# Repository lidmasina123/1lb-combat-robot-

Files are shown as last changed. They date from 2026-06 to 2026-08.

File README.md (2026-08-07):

# Zagitis

**Zagitis** is a 1 lb combat robot with a unique weapon system. Unlike most robots in this weight class, which simply use a spinning weapon mounted directly to the chassis, Zagitis uses an **articulating weapon arm** with a spinning mass mounted at the end.

This allows the weapon to feed into an opponent more effectively, increasing the amount of damage it can deal.

The robot is designed to attack opponents from above, as the top armor on many 1 lb combat robots is significantly weaker than the front or sides.

I chose this design because many modern atveight robots are extremely similar—typically 4WD vertical eggbeaters. Building a robot that is only slightly better than existing designs is both difficult and expensive. Instead, Zagitis is designed to counter this common style by targeting their weaker top armor.





---

# Features

## 1. Fully Brushless Drive

The drive system is completely brushless, providing a better power-to-weight ratio, higher efficiency, and improved reliability.

## 2. Carbon Fiber + TPU Construction

The robot combines carbon fiber with TPU printed parts. This allows it to absorb impacts while remaining structurally rigid.

## 3. Compact Electronics

The robot uses **two Repeat Robotics dual-drive ESCs**, allowing all of the electronics to fit into a very compact chassis.

## 4. Narrow but Wide Design

The robot is narrow from the front while maintaining a wide wheelbase. This reduces the number of exposed sides where opponents can gain an advantage while improving stability.

## 5. 4S Battery

Most 1 lb combat robots run on **3S batteries**.

Zagitis uses a **4S battery** for increased power and faster weapon spin-up.

## 6. Two Configurations

The robot has two interchangeable configurations depending on the opponent.

- Vertical spinner configuration
- Horizontal spinner configuration

## 7. Tangent Drive

Unlike most 1 lb combat robots, which use smaller motors paired with gearboxes, Zagitis uses **tangent drive motors**.

This allows the use of larger, more powerful motors while eliminating the gearbox, reducing complexity and improving efficiency.

---

# Wiring Diagram

wiering diagram

---

# Bill of Materials

| Part | Link | Price | Qty | Total |
|---|---|---:|----:|---:|
| Drive Motors – Tangent 1406 | https://palmbeachbots.com/products/repeat-robotics-tangent-drive-motor-1406-1500kv | $18 | 2 | $36 |
| Arm Motor – 16 mm Brushed Planetary | https://palmbeachbots.com/products/repeat-robotics-16mm-brushed-planetary-motor | $17 | 1 | $17 |
| Weapon Motor – Repeat 2307 | https://www.aliexpress.com/item/1005007338658310.html | $15 | 1 | $15 |
| Repeat Robotics Dual Drive ESC | https://palmbeachbots.com/products/repeat-robotics-am32-dual-brushless-drive-esc-with-bec | $40 | 2 | $80 |
| FlySky FS-i4X Transmitter | https://palmbeachbots.com/products/flysky-fs-i4x-2-4ghz-4-channel-transmitter-with-receiver-afhds2a | $52 | 1 | $52 |
| FS2A Receiver | https://palmbeachbots.com/products/fs2a-4-channel-mini-receiver-afhds-2a-works-with-flysky-fs-i6 | $12 | 1 | $12 |

## Total Cost

**$212 USD**

---

# Assembly

This robot is designed to be easy to assemble and repair, making it quick to service between fights.

## Step 1 – Assemble the Drive Pods

First, assemble the two drive pods.

Each drive pod requires:

- 2 × M4 screws or shoulder bolts for the wheel
- 4 × M2 screws to mount the drive motor

Once assembled, make sure the wheel spins freely.

---

## Step 2 – Assemble the Weapon Arm

You will need:

- 1 × M4 bolt for the arm shaft
- 2 × M2 screws for the arm motor

Attach the arm motor first.

Press the gear onto the motor shaft.

Insert the arm shaft through one side of the chassis, through the arm gear (with both **4×8×3 mm bearings** installed), and out through the opposite side.

Finally, bolt the weapon arm to the arm gear and install the completed assembly into the chassis.

---

## Step 3 – Assemble the Chassis

Attach all mechanical components to the bottom carbon fiber plate using:

- 18 × 2.5 mm wood screws

---

## Step 4 – Install the Electronics

Install both dual-drive ESCs.

Wiring is straightforward:

- Connect each drive motor to one side of a dual-drive ESC.
- Connect both ESC signal wires to the receiver.
- Connect the weapon ESC and weapon motor.
- Connect the battery.
- Verify that all motors spin in the correct direction before securing the wiring.

---

## Step 5 – Finish Assembly

Install the top armor plates and secure them with the screws.

The robot is now fully assembled and ready for testing.

> **Note**
>
> More detailed assembly instructions with photos will be added once all of the parts have arrived and the robot has been fully assembled.

---

# Additional Information

- Approximately **130 g** of filament is required for all printed parts.
- All carbon fiber parts fit within a **100 mm × 200 mm × 1.5 mm** carbon fiber sheet.
- The robot is designed for fast maintenance and easy part replacement between fights.

---

# License

This project is open source.

Feel free to build, modify, and improve the design.

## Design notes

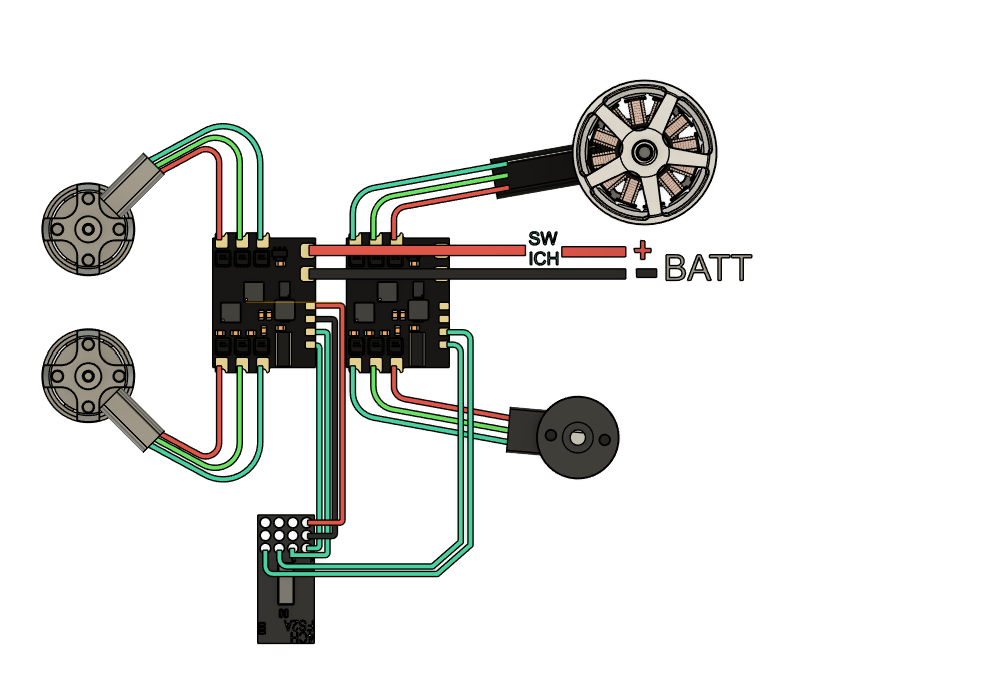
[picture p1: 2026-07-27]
wiering diagram.png

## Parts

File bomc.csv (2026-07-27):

 |  |  |  | bill of materials
part |  | price | quantity
driwe motors tangent 1406 | https://palmbeachbots.com/products/repeat-robotics-tangent-drive-motor-1406-1500kv | 18 | 2 | 36
arm motor 16mm Brushed Planetary Motor | https://palmbeachbots.com/products/repeat-robotics-16mm-brushed-planetary-motor | 17 | 1 | 17
weapon motor repat 2307 | https://www.aliexpress.com/item/1005007338658310.html | 15 | 1 | 15
esc | https://palmbeachbots.com/products/repeat-robotics-am32-dual-brushless-drive-esc-with-bec | 40 | 2 | 80
rc remote | https://palmbeachbots.com/products/flysky-fs-i4x-2-4ghz-4-channel-transmitter-with-receiver-afhds2a | 52 | 1 | 52
reciver | https://palmbeachbots.com/products/fs2a-4-channel-mini-receiver-afhds-2a-works-with-flysky-fs-i6 | 12 | 1 | 12
 |  | totoal | 212

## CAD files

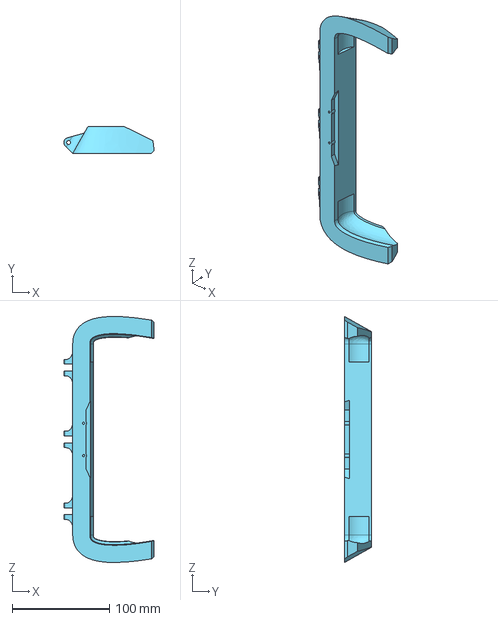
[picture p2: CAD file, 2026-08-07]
cad/cad/main body metal forks.step
93.1 x 27.5 x 253.4 mm

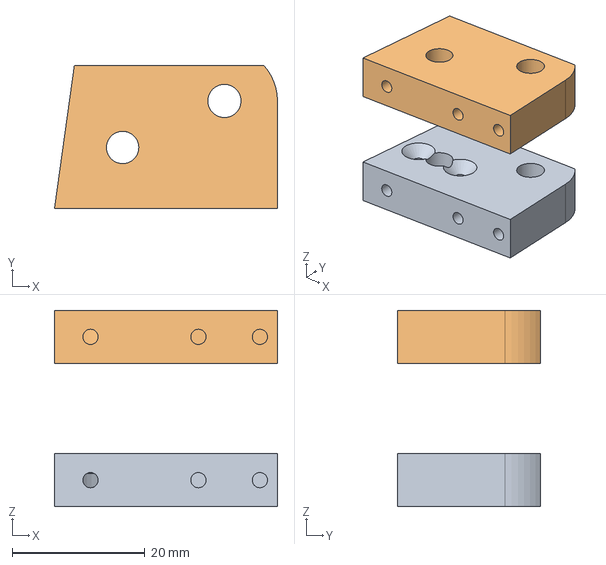
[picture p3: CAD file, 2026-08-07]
cad/cad/arm holder.step
33.6 x 21.5 x 29.6 mm

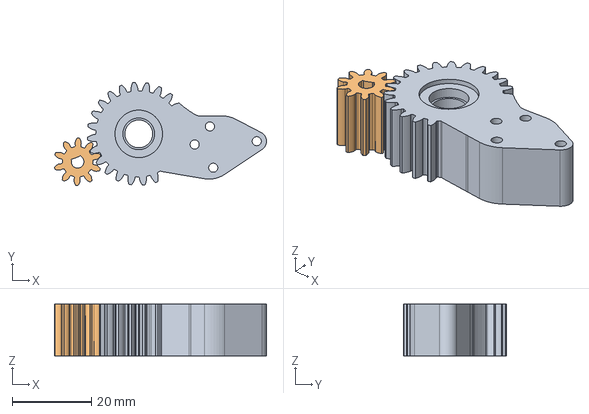
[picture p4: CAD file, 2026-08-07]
cad/cad/gears.step
53.5 x 26.0 x 13.0 mm

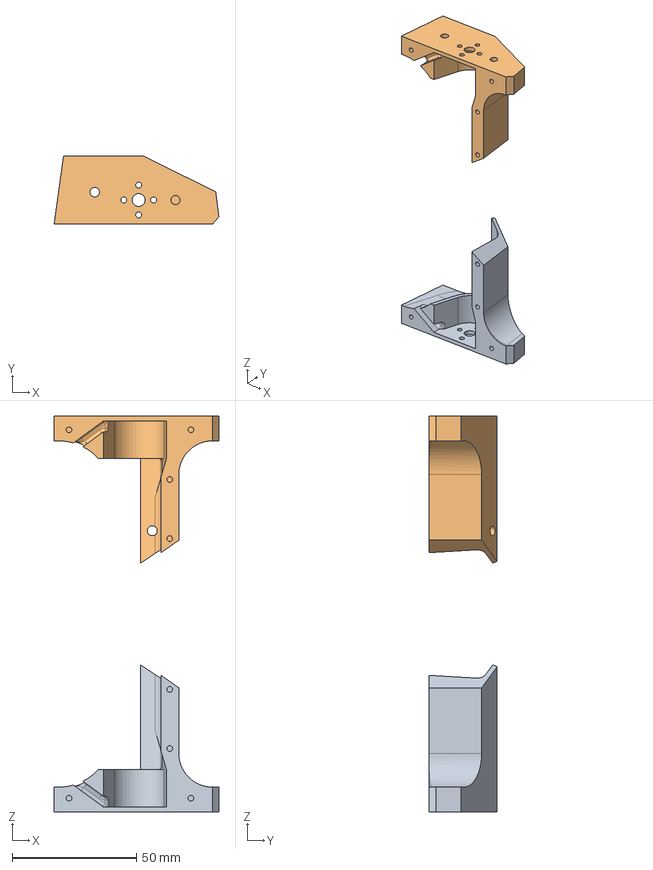
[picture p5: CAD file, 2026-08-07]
cad/cad/driwe pods.step
66.3 x 27.5 x 159.1 mm

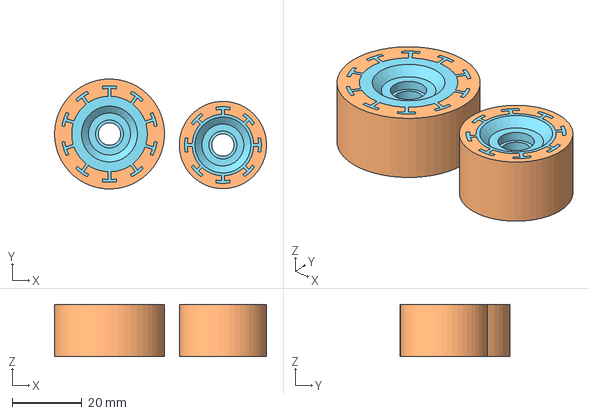
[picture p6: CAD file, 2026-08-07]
cad/cad/wheels (2).step
60.7 x 31.5 x 15.0 mm

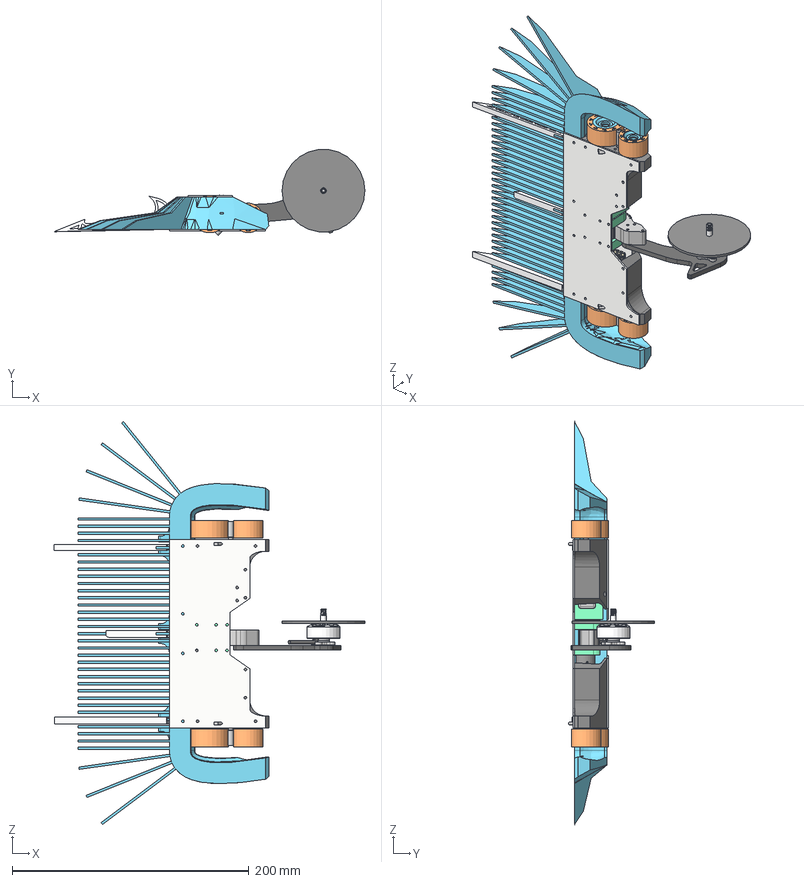
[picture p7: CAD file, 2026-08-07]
cad/cad/zagitis 1lb.step
262.6 x 72.6 x 340.4 mm
main body
fork
battery
socket head cap screw_din_DIN 912 M3 x 6 --- 6N
Repeat Tangent 1406 (Antweight)
ISO 7380-1 - M3 x 6 Steel 4.6 Plain
Wire Reference
Magnets
Coils
Base and Bearings
dysk
Repeat Tangent 1406 (Antweight)_1
PCB
PDFN3333 (DFN8 3.3x3.3) v1 x 12
SOT23-5 v1 x 3
WE_Inductor_4020 v1
VQFN-12 v2
RC1225 v2 x 2
ceramic_cap_0805 v1 x 14
Inner Pin
Middle Pin
Outer Pin
Plastic Block
Main Board
arm (1)
l drive pod(Mirror)
bottom plate
Component65(Mirror) x 2
main body balene
FusionComponent

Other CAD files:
cad/cad/driwe pods.stl
cad/cad/gears.stl
cad/cad/main body metal forks.stl
cad/cad/wheels (2).stl

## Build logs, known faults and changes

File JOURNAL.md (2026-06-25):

title: "1lb combat robot "
author: "Your name (lidmasina123)"
description: "this is a 1lb combat robot that has a saw in the end of an arm to atack opponents from the top"
created_at: "2026-06-12"

        1LB COMBAT ROBOT

the first think i did in this sesson was i researched the components

I found that the best drive motors for my robot would be the Repeat Robotics Compact 1806 22mm Brushless Planetary Motors because I need a lot of drive power to push opponents around the arena.

https://palmbeachbots.com/products/repeat-robotics-compact-1806-22mm-brushless-planetary-motor-beetle-drive

For the battery, I am going to use a GAONENG GNB LiHV 4S 15.2V 380mAh 90C XT30 LiPo battery.

https://www.gaoneng.shop/products/gaoneng-gnb-lihv-4s-15-2v-380mah-90c-xt30-lipo-battery

For the saw, I am going to use an Axisflying 2207.5 brushless motor. It has a very good power-to-weight ratio.

https://www.aliexpress.com/item/1005006344056844.html

For the arm, I am going to use a Micro 16mm 16GA-050 Metal Gearbox Motor (336 RPM) because I already have this motor at home.

https://www.aliexpress.com/item/1005005905317146.html

For the arm ESC, I am going to use a 20A bidirectional brushed ESC with brake functionality because I already have one available.

https://www.aliexpress.com/item/1005008085017227.html

For the saw ESC, I am going to use a PBB Edition Ready to Sky 35A Brushless ESC. I already have a similar ESC available.

https://palmbeachbots.com/products/ready-to-sky-35a-brushless-esc-with-3-5mm-bullet-connectors

For the drive ESC, I am planning to use the Repeat Robotics Dual AM32 ESC.

https://palmbeachbots.com/products/repeat-robotics-am32-dual-brushless-drive-esc-with-bec

For the receiver and transmitter, I am going to use a FlySky FS-i6 because I already own one.

https://www.aliexpress.com/item/1005012028909932.html

Researching and selecting all of these components took approximately 2 hours.

 then i proceedet to finding or desining the cad models for these components
i found the files for the saw motor and driwe motor
https://grabcad.com/library/pacer-2207-v2-motor-2

https://grabcad.com/library/repeat-drive-compact-1

but ge arm motor i had to desin myself



and i was able to find the electronics
https://grabcad.com/library/repeat-am32-dual-brushless-drive-esc-1

https://grabcad.com/library/fs2a-radio-receiver-afhds-2a-protocol-1

and the battery i desined myself

geting the cad files for each component an desining one took about 1.5h

then i started the robots cad proces first step was  arange the motors and electronics



it took several tries but i settled on this beacase everything is very compact

this took 1h

then proseeded first rouf cading Started designing the frame



this took 1.2h

learned how to make gears and make gear reduction for the arm that is 2.2to 1 then i complethed the arm mecanism!






this took 1.5 h

Rear Armor and Motor Guard

I added rear armor and a guard to prevent anything from jamming into the motor.



this took 42minutes

Hammersaw

I switched the weapon motor to the Repeat Robotics 2004 because I think I am going to have weight issues.

Then I looked at weapon designs from other hammersaw robots. I noticed that many of them have very aggressive attack angles and a tooth on the counterweight. Based on that research, I designed my blade.



The blade itself weighs 20 g, but with the motor mounting plate and screws, the total weight will be around 40 g.

I also added a stopper to the arm so the weapon cannot hit the ground.

this took me 1.5h

Wheels

I decided to make custom silicone wheels. To mount the wheels to the motors, I am going to use custom aluminum wheel hubs attached to TPU wheels to help absorb impacts.






Forks

I restricted the fork movement so they cannot get stuck underneath the robot.

I also added a fork in the middle. The idea is that when I drive head-on into an eggbeater spinner, the center fork will deflect the weapon upward and hopefully cause it to stall.


To improve durability, I reinforced the fork mounts with fillets. This should make them stronger and help reduce stress concentrations around the joints.

finishing tuches
Then I added the top plates, screw holes, and chamfers where needed

this took 20 minutes

Then I considered the robot finished. Here are some final renders of the completed design.
  


 Drive System

After considering the power available from Blitz Lite motors, I concluded that traction would likely become the limiting factor. Many hammersaw robots use four-wheel drive to improve traction and control, and the Blitz Lite motors provide more power than a typical 1 lb robot requires. They are also relatively expensive for my budget.

Because of this, I started looking for alternatives that could provide strong drive performance while remaining lightweight and making a 4WD setup easy to implement.

After extensive research, I chose the Repeat Robotics Tangent Drive Motor. It offers approximately 15% more stator volume than the Blitz Lite while weighing less than one-third as much. Since it does not use a gearbox and instead relies on wheel diameter for reduction, it is both lighter and mechanically simpler.

After selecting the motors, I began integrating them into the design. This session focused on the first iteration of the motor installation.


I also changed the battery to a Tattu 450 mAh 4S 75C (14.8 V) pack since I already have one available.

In addition, I switched back to a larger weapon motor and changed the weapon to a grinding disk. This should be more effective against metal armor, and since I already have a 70 mm grinding disk, there is no need to order a custom weapon.
![Uploading Screenshot 2026-06-25 130438.png…]()

 Drive Pods

This session focused on designing the drive pods. I wanted them to be removable and interchangeable to simplify maintenance and repairs.


Chassis


I decided to make the robot wider and shorter. This should make it easier to control opponents and reduce the number of approach angles where I am at a disadvantage.

The robot is now primarily constructed from TPU for the front and armor sections, while the drive pods are made from PA12-CF.

I chose PA12-CF for the drive pods because they need to be stiff and rigid. A softer material could flex under load, causing drivetrain binding or reduced efficiency.

Top Plates and Electronics

This session focused on designing the top plates and integrating the electronics.



The top plates will eventually be manufactured from carbon fiber, although transparent placeholders are currently used in CAD for visibility.

Wheels

This session focused on designing the wheels. They are very similar to those used on the previous version, but they now run on 4×8×3 mm bearings.

For traction, I am using 20A silicone because it is readily available and should provide excellent grip.

Horizontal Spinner Defense

This session focused on developing the front configuration for defending against horizontal spinners. This design is known as a beeline.


The purpose of the beeline is to absorb and deflect impacts from horizontal weapons, helping to protect the drivetrain and internal components.

Final Integration

This session focused on refining the design and improving serviceability.


I created dedicated space for wire routing, added bearings to the arm gear system, and integrated the power switch directly into the chassis design. These changes should improve reliability, simplify assembly, and make maintenance easier.

 and now i think it is finished but i will keep inoraiting 
 


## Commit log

2026-08-07 bom table format
2026-08-07 Create cad files
